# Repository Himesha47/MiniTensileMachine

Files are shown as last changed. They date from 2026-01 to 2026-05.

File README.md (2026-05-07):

# 🔬 MiniTensileMachine

A low-cost, open-source **miniature tensile testing machine** built as a Final Year Research project. The system uses an Arduino-controlled stepper motor to apply tensile load to a specimen, while a Python GUI provides real-time data acquisition, live plotting, and materials analysis.

---

## 📌 Project Overview

Traditional tensile testing machines are expensive and inaccessible for small research labs or educational use. This project demonstrates that accurate tensile testing can be achieved with affordable off-the-shelf components and custom software, making it suitable for polymer films, paper, textiles, and other low-strength materials.

---

## 🛠️ Hardware Components

| Component | Role |
|---|---|
| Arduino Uno | Microcontroller — reads sensors and drives the motor |
| A4988 Stepper Driver | Controls the NEMA stepper motor for precise crosshead movement |
| HX711 Load Cell Amplifier | Amplifies the load cell signal for Arduino |
| Load Cell (strain gauge) | Measures applied force in Newtons |
| NEMA Stepper Motor | Drives the crosshead (UP / DOWN) |
| Custom PCB | Integrates all components cleanly |

---

## 💻 Software

### Python GUI — `tensile_tester_guiV5.py`

The main application (`gui/tensile_tester_guiV5.py`) is a full-featured desktop GUI built with **Tkinter** and **Matplotlib**.

#### Features

- 🔌 **Auto-connect to Arduino** — detects the correct COM port automatically on startup
- ▶️ **Start / Stop test control** — sends commands to Arduino over serial
- ↕️ **Motor direction control** — UP / DOWN before a test begins
- ⚖️ **Tare & Zero Length** — zero the load cell and displacement reference
- 📊 **Live real-time plotting** with 4 selectable graph modes:
  - Force vs Time
  - Displacement vs Time
  - Force vs Displacement
  - Stress vs Strain
- 🗃️ **Six live metric cards** — Current Force, Current Displacement, Peak Force, Peak Displacement, Break Force, Young's Modulus
- 🧮 **Automatic calculations**:
  - Cross-sectional area (Width × Thickness)
  - Engineering stress (Force / Area)
  - Engineering strain (Displacement / L₀)
  - Young's Modulus (least-squares fit over elastic region)
- 💥 **Fracture detection** — automatically stops the test when force drops >30% from peak
- 📁 **Export** — saves data as `.csv` and the current graph as a high-res `.png` into `results/`
- 🔄 **40-point moving average** — smooths noisy sensor readings in real time

---

## 📂 Project Structure

```
MiniTensileMachine/
│
├── firmware/
│   ├── tensile_machine/           # Active firmware (upload this to the Arduino)
│   │   └── tensile_machine.ino
│   └── archive/                   # Earlier experimental sketches (reference only)
│
├── gui/
│   ├── tensile_tester_guiV5.py   # Main Python GUI application
│   └── archive/                   # Older GUI versions (reference only)
│
├── hardware/
│   └── pcb/                       # KiCad PCB and schematic files
│
├── data/
│   └── specimens/                 # Raw .txt data from manual test runs
│
├── results/                       # Exported test data (CSV + PNG plots, git-ignored)
│   └── .gitkeep
│
├── requirements.txt               # Python dependencies
└── README.md
```

---

## ⚙️ Setup & Usage

### Requirements

- Python 3.8+ with `tkinter` (included with standard Python on Windows)
- Install dependencies:

```bash
pip install -r requirements.txt
```

### Running the Application

1. Upload `firmware/tensile_machine/tensile_machine.ino` to the Arduino Uno.
2. Connect the Arduino via USB.
3. Run the GUI:

```bash
cd gui
python tensile_tester_guiV5.py
```

4. The app will auto-detect the Arduino on the correct COM port.

### Performing a Test

1. (Optional) Enter **L₀**, **Width**, and **Thickness** for stress/strain calculations.
2. Select the desired **graph type** from the dropdown.
3. Click **TARE** to zero the load cell and **ZERO LEN** to zero the displacement.
4. Set the motor direction (**DIR UP** to pull the specimen).
5. Click **▶ START** to begin the test.
6. The machine will automatically stop when fracture is detected.
7. Click **EXPORT** to save the data and plot — the dialog opens in `results/` by default.

---

## 📈 Measured Outputs

| Parameter | Unit | Description |
|---|---|---|
| Force | N | Applied tensile load |
| Displacement | mm | Crosshead travel distance |
| Stress | MPa | Force / Cross-sectional area |
| Strain | — | Displacement / Gauge length (L₀) |
| Young's Modulus | MPa | Slope of the elastic region (E = σ/ε) |
| Peak Force | N | Maximum force reached during the test |
| Break Force | N | Force at the moment of specimen fracture |

---

## 📡 Serial Communication Protocol

The Arduino sends comma-separated data lines at 9600 baud:

```
t_ms,force_N,disp_mm       ← header sent at boot
1234,5.62,0.031             ← data line (time ms, force N, displacement mm)
```

The GUI sends text commands to the Arduino:

| Command | Action |
|---|---|
| `START` | Begin test (motor ON, data streaming) |
| `STOP` | Stop motor |
| `DIR UP` | Set motor direction to UP (tension) |
| `DIR DOWN` | Set motor direction to DOWN |
| `TARE` | Zero the load cell |
| `ZERO_LEN` | Zero the displacement sensor |

---

## 📸 Screenshots

> Exported test plots and data are saved to the `results/` folder.

---

## 👨‍🔬 Author

Final Year Research Project — Department of Physics 
Built with Arduino, Python, and custom PCB hardware.

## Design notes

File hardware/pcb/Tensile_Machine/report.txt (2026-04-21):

Info: Processing symbol 'A1:Module:Arduino_UNO_R3'.
Info: Processing symbol 'A2:Module:Pololu_Breakout-16_15.2x20.3mm'.
Info: Processing symbol 'C1:Capacitor_THT:C_Disc_D5.0mm_W2.5mm_P2.50mm'.
Info: Processing symbol 'C2:Capacitor_THT:CP_Radial_D8.0mm_P3.50mm'.
Info: Processing symbol 'J1:TerminalBlock:TerminalBlock_Xinya_XY308-2.54-4P_1x04_P2.54mm_Horizontal'.
Info: Processing symbol 'J2:TerminalBlock:TerminalBlock_Xinya_XY308-2.54-4P_1x04_P2.54mm_Horizontal'.
Info: Processing symbol 'J3:TerminalBlock:TerminalBlock_Xinya_XY308-2.54-2P_1x02_P2.54mm_Horizontal'.
Info: Processing symbol 'J4:TerminalBlock:TerminalBlock_Xinya_XY308-2.54-4P_1x04_P2.54mm_Horizontal'.
Info: Processing symbol 'J5:TerminalBlock:TerminalBlock_Xinya_XY308-2.54-4P_1x04_P2.54mm_Horizontal'.
Add net unconnected-(A1-D2-Pad17).
Connected A1 pin 17 to unconnected-(A1-D2-Pad17).
Add net Net-(A1-D5).
Connected A1 pin 20 to Net-(A1-D5).
Add net unconnected-(A1-IOREF-Pad2).
Connected A1 pin 2 to unconnected-(A1-IOREF-Pad2).
Add net unconnected-(A1-AREF-Pad30).
Connected A1 pin 30 to unconnected-(A1-AREF-Pad30).
Add net /HX_DT.
Connected A1 pin 23 to /HX_DT.
Add net unconnected-(A1-3V3-Pad4).
Connected A1 pin 4 to unconnected-(A1-3V3-Pad4).
Add net unconnected-(A1-D7-Pad22).
Connected A1 pin 22 to unconnected-(A1-D7-Pad22).
Add net unconnected-(A1-D10-Pad25).
Connected A1 pin 25 to unconnected-(A1-D10-Pad25).
Add net unconnected-(A1-D6-Pad21).
Connected A1 pin 21 to unconnected-(A1-D6-Pad21).
Add net /DIR.
Connected A1 pin 19 to /DIR.
Add net unconnected-(A1-A3-Pad12).
Connected A1 pin 12 to unconnected-(A1-A3-Pad12).
Add net unconnected-(A1-NC-Pad1).
Connected A1 pin 1 to unconnected-(A1-NC-Pad1).
Add net unconnected-(A1-D13-Pad28).
Connected A1 pin 28 to unconnected-(A1-D13-Pad28).
Add net unconnected-(A1-D11-Pad26).
Connected A1 pin 26 to unconnected-(A1-D11-Pad26).
Add net unconnected-(A1-SDA/A4-Pad31).
Connected A1 pin 31 to unconnected-(A1-SDA/A4-Pad31).
Add net unconnected-(A1-D1/TX-Pad16).
Connected A1 pin 16 to unconnected-(A1-D1/TX-Pad16).
Add net +5V.
Connected A1 pin 5 to +5V.
Add net unconnected-(A1-A2-Pad11).
Connected A1 pin 11 to unconnected-(A1-A2-Pad11).
Add net unconnected-(A1-D12-Pad27).
Connected A1 pin 27 to unconnected-(A1-D12-Pad27).
Add net unconnected-(A1-A1-Pad10).
Connected A1 pin 10 to unconnected-(A1-A1-Pad10).
Add net /STEP.
Connected A1 pin 18 to /STEP.
Add net unconnected-(A1-~{RESET}-Pad3).
Connected A1 pin 3 to unconnected-(A1-~{RESET}-Pad3).
Add net GND.
Connected A1 pin 29 to GND.
Add net unconnected-(A1-SDA/A4-Pad13).
Connected A1 pin 13 to unconnected-(A1-SDA/A4-Pad13).
Add net unconnected-(A1-D0/RX-Pad15).
Connected A1 pin 15 to unconnected-(A1-D0/RX-Pad15).
Add net unconnected-(A1-VIN-Pad8).
Connected A1 pin 8 to unconnected-(A1-VIN-Pad8).
Add net unconnected-(A1-SCL/A5-Pad32).
Connected A1 pin 32 to unconnected-(A1-SCL/A5-Pad32).
Connected A1 pin 7 to GND.
Add net unconnected-(A1-SCL/A5-Pad14).
Connected A1 pin 14 to unconnected-(A1-SCL/A5-Pad14).
Add net unconnected-(A1-A0-Pad9).
Connected A1 pin 9 to unconnected-(A1-A0-Pad9).
Connected A1 pin 6 to GND.
Add net /HX_SCK.
Connected A1 pin 24 to /HX_SCK.
Updated A1 unit metadata.
Added A2 (footprint 'Module:Pololu_Breakout-16_15.2x20.3mm').
Changed REF** reference designator to A2.
Changed A2 value from Pololu_Breakout-16_15.2x20.3mm to Pololu_Breakout_A4988.
Updated A2 symbol association from  to /9ce11f0a-daac-48ad-9ff5-aed24f605efb.
Updated A2 fields.
Updated A2 sheetname to '/'.
Updated A2 sheetfile to 'Tensile_Machine.kicad_sch'.
Updated A2 footprint filters to 'Pololu*Breakout*15.2x20.3mm*'.
Connected A2 pin 15 to /STEP.
Connected A2 pin 11 to +5V.
Connected A2 pin 2 to +5V.
Add net +12V.
Connected A2 pin 8 to +12V.
Connected A2 pin 13 to +5V.
Connected A2 pin 16 to /DIR.
Connected A2 pin 12 to GND.
Connected A2 pin 10 to +5V.
Connected A2 pin 7 to GND.
Add net /1B.
Connected A2 pin 3 to /1B.
Connected A2 pin 9 to Net-(A1-D5).
Connected A2 pin 14 to +5V.
Add net /2B.
Connected A2 pin 6 to /2B.
Add net /2A.
Connected A2 pin 5 to /2A.
Add net /1A.
Connected A2 pin 4 to /1A.
Connected A2 pin 1 to GND.
Updated A2 unit metadata.
Added A1 (footprint 'Module:Arduino_UNO_R3').
Added C1 (footprint 'Capacitor_THT:C_Disc_D5.0mm_W2.5mm_P2.50mm').
Changed REF** reference designator to C1.
Changed C1 value from C_Disc_D5.0mm_W2.5mm_P2.50mm to 0.1uF.
Updated C1 symbol association from  to /a392f29e-6ea6-410c-80fb-69ff1eea6aba.
Updated C1 fields.
Updated C1 sheetname to '/'.
Updated C1 sheetfile to 'Tensile_Machine.kicad_sch'.
Updated C1 footprint filters to 'C_*'.
Connected C1 pin 1 to +5V.
Connected C1 pin 2 to GND.
Updated C1 unit metadata.
Changed REF** reference designator to A1.
Added C2 (footprint 'Capacitor_THT:CP_Radial_D8.0mm_P3.50mm').
Changed REF** reference designator to C2.
Changed C2 value from CP_Radial_D8.0mm_P3.50mm to 470uF.
Updated C2 symbol association from  to /1f514063-8875-4d03-a3e9-da0d240c9436.
Updated C2 fields.
Updated C2 sheetname to '/'.
Updated C2 sheetfile to 'Tensile_Machine.kicad_sch'.
Updated C2 footprint filters to 'CP_*'.
Connected C2 pin 2 to GND.
Connected C2 pin 1 to +12V.
Updated C2 unit metadata.
Updated A1 symbol association from  to /e0d1e556-8547-4fa6-a76f-a9a0838d3b23.
Added J1 (footprint 'TerminalBlock:TerminalBlock_Xinya_XY308-2.54-4P_1x04_P2.54mm_Horizontal').
Changed REF** reference designator to J1.
Changed J1 value from TerminalBlock_Xinya_XY308-2.54-4P_1x04_P2.54mm_Horizontal to Stepper motor.
Updated J1 symbol association from  to /26a67c83-a84e-4405-9260-f3302d5805dd.
Updated J1 fields.
Updated J1 sheetname to '/'.
Updated J1 sheetfile to 'Tensile_Machine.kicad_sch'.
Updated J1 footprint filters to 'Connector*:*_1x??_*'.
Connected J1 pin 1 to /1B.
Connected J1 pin 3 to /2A.
Connected J1 pin 4 to /2B.
Connected J1 pin 2 to /1A.
Updated J1 unit metadata.
Updated A1 fields.
Added J2 (footprint 'TerminalBlock:TerminalBlock_Xinya_XY308-2.54-4P_1x04_P2.54mm_Horizontal').
Changed REF** reference designator to J2.
Changed J2 value from TerminalBlock_Xinya_XY308-2.54-4P_1x04_P2.54mm_Horizontal to Load cell.
Updated J2 symbol association from  to /47c7611e-49ea-4230-a9ca-6c8d696261cc.
Updated J2 fields.
Updated J2 sheetname to '/'.
Updated J2 sheetfile to 'Tensile_Machine.kicad_sch'.
Updated J2 footprint filters to 'Connector*:*_1x??_*'.
Add net Net-(J2-Pin_1).
Connected J2 pin 1 to Net-(J2-Pin_1).
Add net Net-(J2-Pin_4).
Connected J2 pin 4 to Net-(J2-Pin_4).
Add net Net-(J2-Pin_2).
Connected J2 pin 2 to Net-(J2-Pin_2).
Add net Net-(J2-Pin_3).
Connected J2 pin 3 to Net-(J2-Pin_3).
Updated J2 unit metadata.
Updated A1 sheetname to '/'.
Added J3 (footprint 'TerminalBlock:TerminalBlock_Xinya_XY308-2.54-2P_1x02_P2.54mm_Horizontal').
Changed REF** reference designator to J3.
Changed J3 value from TerminalBlock_Xinya_XY308-2.54-2P_1x02_P2.54mm_Horizontal to Power supply.
Updated J3 symbol association from  to /e6d3ee77-a735-4ffe-a698-87d4fa4ca9e0.
Updated J3 fields.
Updated J3 sheetname to '/'.
Updated J3 sheetfile to 'Tensile_Machine.kicad_sch'.
Updated J3 footprint filters to 'Connector*:*_1x??_*'.
Connected J3 pin 2 to GND.
Connected J3 pin 1 to +12V.
Updated J3 unit metadata.
Updated A1 sheetfile to 'Tensile_Machine.kicad_sch'.
Added J4 (footprint 'TerminalBlock:TerminalBlock_Xinya_XY308-2.54-4P_1x04_P2.54mm_Horizontal').
Changed REF** reference designator to J4.
Changed J4 value from TerminalBlock_Xinya_XY308-2.54-4P_1x04_P2.54mm_Horizontal to HX711_LOAD.
Updated J4 symbol association from  to /d505f5b6-755c-469a-85d0-f86fedeb9e4e.
Updated J4 fields.
Updated J4 sheetname to '/'.
Updated J4 sheetfile to 'Tensile_Machine.kicad_sch'.
Updated J4 footprint filters to 'Connector*:*_1x??_*'.
Connected J4 pin 4 to Net-(J2-Pin_4).
Connected J4 pin 2 to Net-(J2-Pin_2).
Connected J4 pin 1 to Net-(J2-Pin_1).
Connected J4 pin 3 to Net-(J2-Pin_3).
Updated J4 unit metadata.
Updated A1 footprint filters to 'Arduino*UNO*R3*'.
Added J5 (footprint 'TerminalBlock:TerminalBlock_Xinya_XY308-2.54-4P_1x04_P2.54mm_Horizontal').
Changed REF** reference designator to J5.
Changed J5 value from TerminalBlock_Xinya_XY308-2.54-4P_1x04_P2.54mm_Horizontal to HX711_CTRL.
Updated J5 symbol association from  to /12e2f7dd-3db3-4ff2-9b89-f2648dfc7185.
Updated J5 fields.
Updated J5 sheetname to '/'.
Updated J5 sheetfile to 'Tensile_Machine.kicad_sch'.
Updated J5 footprint filters to 'Connector*:*_1x??_*'.
Connected J5 pin 4 to GND.
Connected J5 pin 3 to /HX_SCK.
Connected J5 pin 1 to +5V.
Connected J5 pin 2 to /HX_DT.
Updated J5 unit metadata.

Info: Total warnings: 0, errors: 0.

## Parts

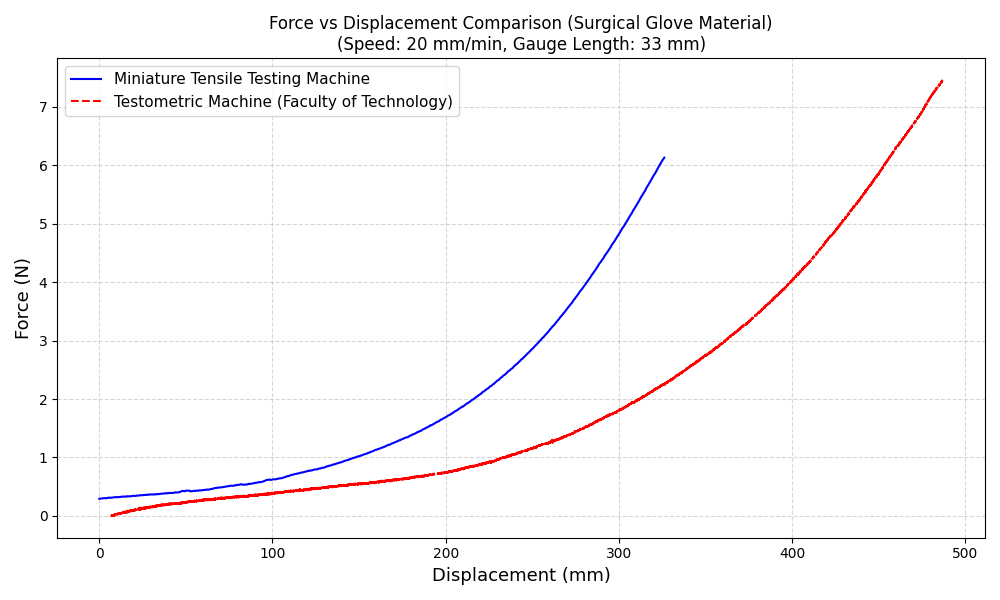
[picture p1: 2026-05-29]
MiniTensileMachine_Results/Glove Material/Glove_Comparison_FvD.png

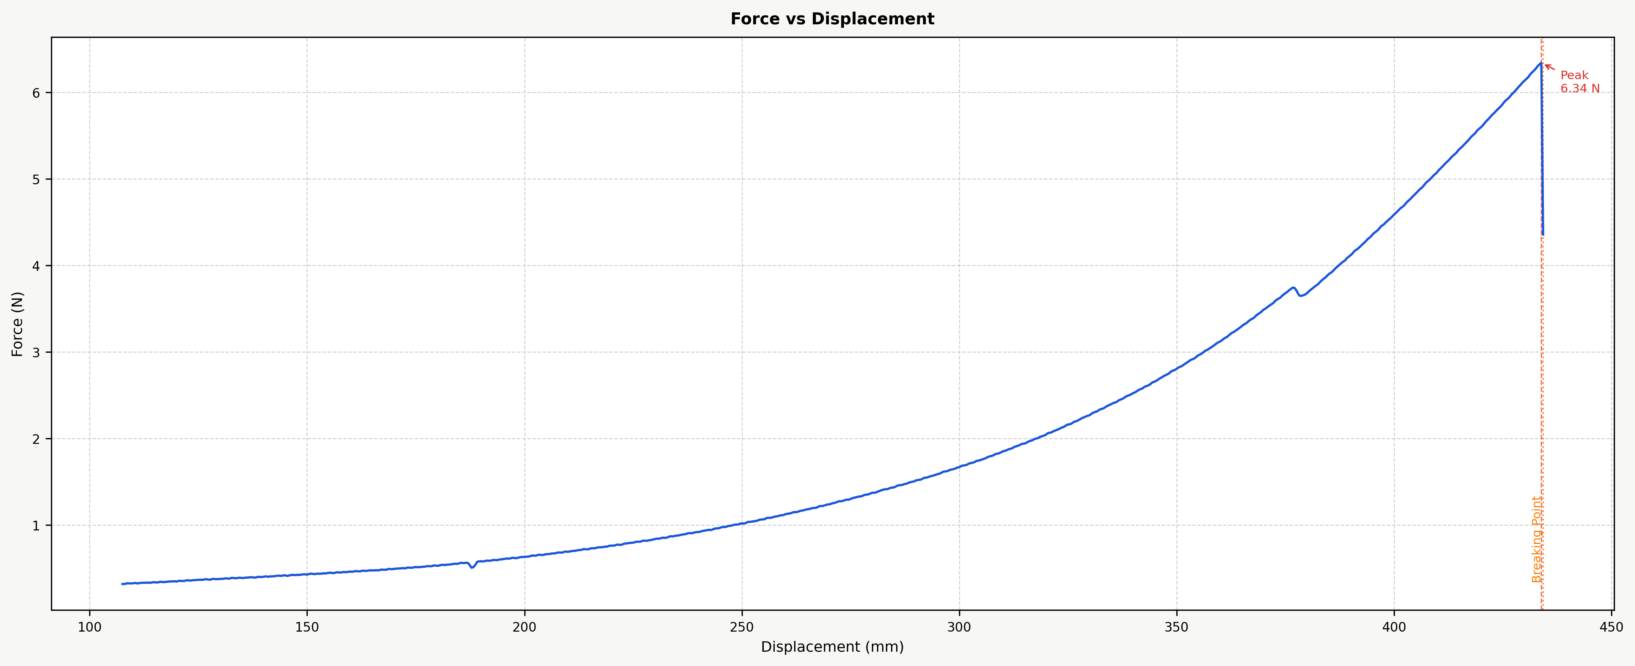
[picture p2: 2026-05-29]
MiniTensileMachine_Results/Glove Material/Glove2.png

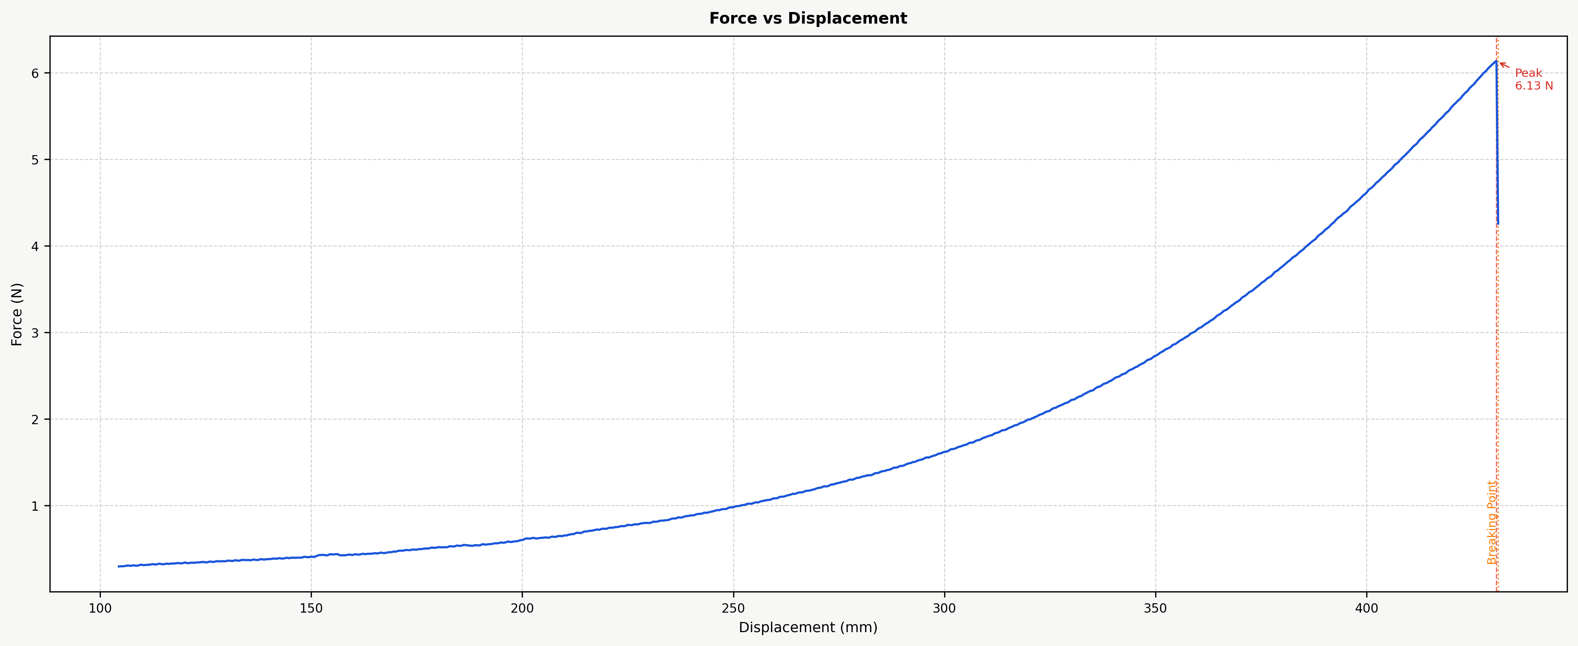
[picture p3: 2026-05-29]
MiniTensileMachine_Results/Glove Material/Glove3.png

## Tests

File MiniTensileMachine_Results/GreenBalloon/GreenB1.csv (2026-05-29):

Time (s) | Force (N) | Displacement (mm) | Strain | Stress (MPa)
476.732 | 0.6017125000000014 | 135.33047875 | 5.41321915 | 0.557141203703705
476.782 | 0.6018000000000014 | 135.34681375 | 5.41387255 | 0.5572222222222235
476.832 | 0.6018875000000014 | 135.36314875 | 5.41452595 | 0.557303240740742
476.882 | 0.6019125000000013 | 135.37948375000002 | 5.415179350000001 | 0.5573263888888901
476.932 | 0.6019375000000013 | 135.39582625 | 5.41583305 | 0.5573495370370383
476.982 | 0.6018500000000013 | 135.4121625 | 5.4164864999999995 | 0.5572685185185197
477.032 | 0.6017625000000013 | 135.42849875 | 5.417139949999999 | 0.5571875000000012
477.082 | 0.6016875000000013 | 135.444835 | 5.417793400000001 | 0.5571180555555567
477.132 | 0.6016125000000013 | 135.46117125 | 5.4184468500000005 | 0.5570486111111123
477.182 | 0.6015500000000014 | 135.4775075 | 5.4191003 | 0.556990740740742
477.232 | 0.6014875000000013 | 135.49384875 | 5.4197539500000005 | 0.5569328703703715
477.282 | 0.6015750000000013 | 135.510185 | 5.4204074 | 0.55701388888889
477.332 | 0.6016625000000013 | 135.52652125 | 5.42106085 | 0.5570949074074086
477.382 | 0.6019000000000013 | 135.5428575 | 5.4217143 | 0.557314814814816
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

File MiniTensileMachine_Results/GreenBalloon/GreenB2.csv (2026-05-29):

Time (s) | Force (N) | Displacement (mm) | Strain | Stress (MPa)
504.184 | 0.7915500000000021 | 160.18692249999998 | 6.407476899999999 | 0.7329166666666685
504.234 | 0.7916500000000021 | 160.2032575 | 6.4081303 | 0.7330092592592611
504.284 | 0.7916750000000021 | 160.21959375 | 6.4087837500000004 | 0.7330324074074094
504.334 | 0.7917000000000021 | 160.23593625 | 6.40943745 | 0.7330555555555575
504.384 | 0.7916625000000022 | 160.2522725 | 6.4100909 | 0.7330208333333352
504.434 | 0.7916250000000021 | 160.26860875 | 6.41074435 | 0.732986111111113
504.484 | 0.791612500000002 | 160.284945 | 6.4113978 | 0.7329745370370389
504.534 | 0.7916000000000021 | 160.30128125000002 | 6.412051250000001 | 0.7329629629629648
504.584 | 0.7915500000000021 | 160.3176225 | 6.4127049 | 0.7329166666666685
504.634 | 0.7915000000000021 | 160.33396375 | 6.413358550000001 | 0.7328703703703723
504.684 | 0.7912500000000021 | 160.3503 | 6.4140120000000005 | 0.7326388888888908
504.734 | 0.791000000000002 | 160.36663625 | 6.41466545 | 0.7324074074074093
504.784 | 0.790712500000002 | 160.3829725 | 6.4153189 | 0.7321412037037055
504.834 | 0.790425000000002 | 160.39930875 | 6.41597235 | 0.7318750000000018
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

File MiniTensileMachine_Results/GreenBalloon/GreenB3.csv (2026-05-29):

Time (s) | Force (N) | Displacement (mm) | Strain | Stress (MPa)
465.312 | 0.7429625000000026 | 147.42101 | 5.896840399999999 | 0.6879282407407431
465.362 | 0.7428625000000026 | 147.437345 | 5.8974937999999995 | 0.6878356481481506
465.412 | 0.7427625000000028 | 147.45368000000002 | 5.8981472 | 0.687743055555558
465.462 | 0.7428000000000028 | 147.47001625000001 | 5.898800650000001 | 0.6877777777777803
465.512 | 0.7428375000000027 | 147.4863525 | 5.899454100000001 | 0.6878125000000025
465.562 | 0.7429250000000027 | 147.50268875 | 5.90010755 | 0.687893518518521
465.612 | 0.7430125000000027 | 147.51903124999998 | 5.9007612499999995 | 0.6879745370370395
465.662 | 0.7431500000000028 | 147.5353675 | 5.9014147 | 0.6881018518518544
465.712 | 0.7432875000000028 | 147.55170375 | 5.90206815 | 0.6882291666666692
465.762 | 0.7434250000000027 | 147.56804 | 5.9027216 | 0.6883564814814839
465.812 | 0.7435625000000027 | 147.58437625 | 5.903375049999999 | 0.6884837962962987
465.862 | 0.7436625000000027 | 147.60071125 | 5.904028449999999 | 0.6885763888888913
465.912 | 0.7437625000000028 | 147.6170525 | 5.9046821 | 0.688668981481484
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

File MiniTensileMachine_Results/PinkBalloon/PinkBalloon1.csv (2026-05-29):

Time (s) | Force (N) | Displacement (mm) | Strain | Stress (MPa)
593.493 | 1.3607500000000012 | 173.9656975 | 5.798856583333333 | 0.22679166666666686
593.543 | 1.3611000000000013 | 173.98203375 | 5.799401125 | 0.22685000000000022
593.593 | 1.3613875000000013 | 173.99837 | 5.799945666666667 | 0.2268979166666669
593.643 | 1.3616750000000013 | 174.0147125 | 5.800490416666666 | 0.22694583333333354
593.693 | 1.3618500000000013 | 174.0310475 | 5.801034916666667 | 0.22697500000000023
593.743 | 1.3620250000000014 | 174.0473825 | 5.801579416666667 | 0.2270041666666669
593.793 | 1.3620875000000012 | 174.0637175 | 5.802123916666667 | 0.22701458333333355
593.843 | 1.362150000000001 | 174.08005375 | 5.802668458333333 | 0.22702500000000017
593.893 | 1.3622625000000013 | 174.09638999999999 | 5.8032129999999995 | 0.2270437500000002
593.943 | 1.3623750000000012 | 174.11272624999998 | 5.803757541666666 | 0.2270625000000002
593.993 | 1.3624500000000013 | 174.12905625000002 | 5.804301875000001 | 0.22707500000000022
594.043 | 1.362525000000001 | 174.14538625 | 5.804846208333333 | 0.2270875000000002
594.093 | 1.3626250000000013 | 174.16171624999998 | 5.805390541666666 | 0.22710416666666688
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

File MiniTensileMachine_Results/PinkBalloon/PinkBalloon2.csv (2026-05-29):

Time (s) | Force (N) | Displacement (mm) | Strain | Stress (MPa)
333.288 | 0.9214625000000012 | 104.67060375000001 | 3.4890201250000006 | 0.15357708333333353
333.338 | 0.9213625000000013 | 104.68693875 | 3.489564625 | 0.1535604166666669
333.388 | 0.9212625000000013 | 104.70326875 | 3.4901089583333333 | 0.15354375000000023
333.438 | 0.9213500000000012 | 104.71959875 | 3.490653291666667 | 0.15355833333333355
333.488 | 0.9214375000000011 | 104.73592875 | 3.491197625 | 0.15357291666666686
333.538 | 0.9215625000000012 | 104.75225875000001 | 3.491741958333334 | 0.1535937500000002
333.588 | 0.9216875000000012 | 104.768595 | 3.4922865 | 0.15361458333333353
333.639 | 0.9219250000000013 | 104.78493125 | 3.492831041666667 | 0.1536541666666669
333.689 | 0.9221625000000012 | 104.8012675 | 3.493375583333333 | 0.1536937500000002
333.739 | 0.9225125000000013 | 104.81760249999999 | 3.4939200833333333 | 0.15375208333333354
333.789 | 0.9228625000000011 | 104.8339375 | 3.4944645833333334 | 0.15381041666666687
333.839 | 0.9232125000000011 | 104.8502725 | 3.4950090833333336 | 0.1538687500000002
333.889 | 0.9235625000000012 | 104.86661375000001 | 3.495553791666667 | 0.15392708333333352
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

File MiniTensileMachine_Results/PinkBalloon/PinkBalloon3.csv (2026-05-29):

Time (s) | Force (N) | Displacement (mm) | Strain | Stress (MPa)
285.708 | 0.820274999999999 | 88.72663374999999 | 2.957554458333333 | 0.13671249999999982
285.758 | 0.8205249999999988 | 88.74297 | 2.958099 | 0.13675416666666648
285.808 | 0.8207499999999989 | 88.75930625 | 2.9586435416666665 | 0.13679166666666648
285.858 | 0.8209749999999989 | 88.7756475 | 2.95918825 | 0.13682916666666647
285.908 | 0.8211874999999991 | 88.79198249999999 | 2.9597327499999997 | 0.13686458333333318
285.958 | 0.821399999999999 | 88.8083175 | 2.96027725 | 0.13689999999999983
286.008 | 0.821512499999999 | 88.8246525 | 2.96082175 | 0.13691874999999984
286.058 | 0.8216249999999989 | 88.84098750000001 | 2.96136625 | 0.13693749999999982
286.108 | 0.821812499999999 | 88.85732375 | 2.961910791666667 | 0.13696874999999983
286.158 | 0.821999999999999 | 88.87366 | 2.962455333333333 | 0.13699999999999982
286.208 | 0.822162499999999 | 88.88999 | 2.9629996666666667 | 0.13702708333333316
286.258 | 0.822324999999999 | 88.90632000000001 | 2.963544 | 0.1370541666666665
286.308 | 0.822537499999999 | 88.92265 | 2.9640883333333337 | 0.13708958333333318
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

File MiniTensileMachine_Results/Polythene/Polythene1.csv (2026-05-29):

Time (s) | Force (N) | Displacement (mm) | Strain | Stress (MPa)
14.878 | 0.26102500000000217 | 0.32335875000000003 | 0.01293435 | 1.4186141304347943
14.928 | 0.31146250000000214 | 0.334955 | 0.0133982 | 1.6927309782608813
14.978 | 0.36190000000000216 | 0.34675625 | 0.013870249999999999 | 1.9668478260869684
15.028 | 0.4156375000000022 | 0.3587625 | 0.014350499999999999 | 2.258899456521751
15.078 | 0.4693750000000022 | 0.37097375 | 0.01483895 | 2.550951086956534
15.128 | 0.5247875000000022 | 0.38339 | 0.0153356 | 2.8521059782608815
24.032 | 0.5165000000000022 | 0.43215125 | 0.01728605 | 2.807065217391316
24.082 | 0.5081875000000022 | 0.48111750000000003 | 0.0192447 | 2.761888586956534
24.132 | 0.49001250000000224 | 0.53028875 | 0.02121155 | 2.6631114130434903
24.182 | 0.47183750000000224 | 0.57966 | 0.0231864 | 2.564334239130447
24.232 | 0.4534750000000022 | 0.62923625 | 0.025169450000000003 | 2.4645380434782727
24.282 | 0.4350875000000022 | 0.6790174999999999 | 0.027160699999999996 | 2.3646059782608813
24.332 | 0.4165375000000022 | 0.7290037500000001 | 0.029160150000000003 | 2.2637907608695773
24.382 | 0.3979750000000022 | 0.779195 | 0.0311678 | 2.1629076086956642
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

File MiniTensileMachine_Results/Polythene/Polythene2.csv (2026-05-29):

Time (s) | Force (N) | Displacement (mm) | Strain | Stress (MPa)
20.095 | -2.215562499999997 | 0.2619725 | 0.0104789 | -12.041100543478246
20.145 | -2.216212499999997 | 0.27241375 | 0.01089655 | -12.044633152173898
20.195 | -2.216749999999997 | 0.28306 | 0.0113224 | -12.047554347826072
20.245 | -2.217299999999997 | 0.29391124999999996 | 0.011756449999999998 | -12.050543478260854
20.295 | -2.217699999999997 | 0.3049675 | 0.0121987 | -12.052717391304332
20.346 | -2.218099999999997 | 0.31622875 | 0.01264915 | -12.05489130434781
20.396 | -2.218574999999997 | 0.32769499999999996 | 0.013107799999999998 | -12.05747282608694
20.446 | -2.219087499999997 | 0.33936625 | 0.013574649999999999 | -12.060258152173898
20.496 | -2.219574999999997 | 0.35124374999999997 | 0.014049749999999998 | -12.062907608695637
20.546 | -2.2200499999999974 | 0.36332624999999996 | 0.014533049999999999 | -12.065489130434768
20.596 | -2.220449999999997 | 0.37561374999999997 | 0.01502455 | -12.067663043478245
20.646 | -2.2208374999999974 | 0.3881 | 0.015524 | -12.069769021739116
20.696 | -2.221137499999997 | 0.40079125 | 0.016031649999999998 | -12.071399456521723
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

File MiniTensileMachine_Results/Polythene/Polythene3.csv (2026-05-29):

Time (s) | Force (N) | Displacement (mm) | Strain | Stress (MPa)
16.451 | -1.2279124999999969 | 0.11179125000000001 | 0.004471650000000001 | -6.673437499999983
16.501 | -1.200249999999997 | 0.11865250000000001 | 0.0047461000000000005 | -6.52309782608694
16.551 | -1.172587499999997 | 0.1257125 | 0.0050285 | -6.372758152173897
16.601 | -1.142987499999997 | 0.13297874999999998 | 0.005319149999999999 | -6.211888586956505
16.651 | -1.1133874999999969 | 0.14045000000000002 | 0.005618000000000001 | -6.051019021739114
16.701 | -1.081874999999997 | 0.14812625 | 0.005925049999999999 | -5.879755434782592
16.751 | -1.050362499999997 | 0.15600750000000002 | 0.006240300000000001 | -5.70849184782607
16.801 | -1.017024999999997 | 0.1640875 | 0.0065635 | -5.527309782608679
16.851 | -0.983687499999997 | 0.17237249999999998 | 0.006894899999999999 | -5.346127717391289
16.901 | -0.948637499999997 | 0.18086249999999998 | 0.0072345 | -5.155638586956505
16.951 | -0.913587499999997 | 0.1895575 | 0.007582299999999999 | -4.965149456521723
17.001 | -0.8768124999999969 | 0.1984575 | 0.0079383 | -4.76528532608694
17.051 | -0.840037499999997 | 0.2075625 | 0.0083025 | -4.565421195652157
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

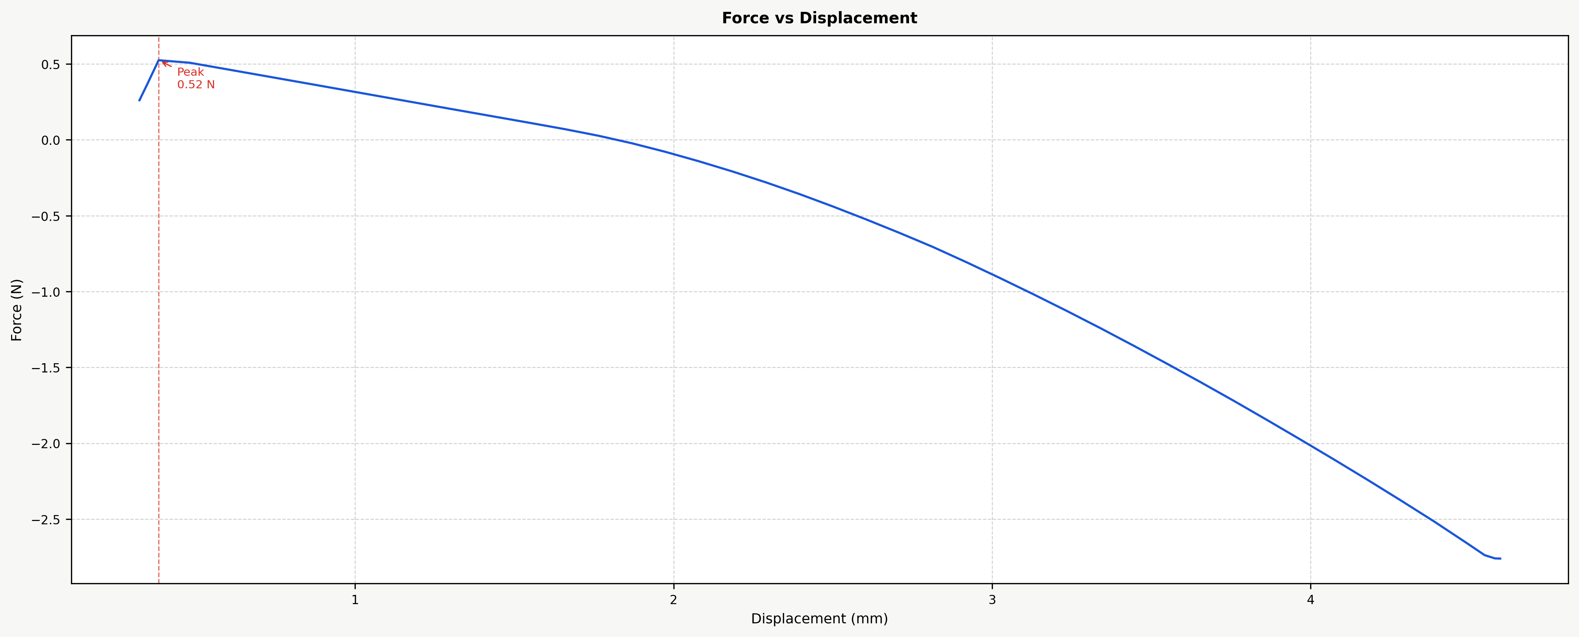
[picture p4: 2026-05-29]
MiniTensileMachine_Results/Polythene/Polythene1.png

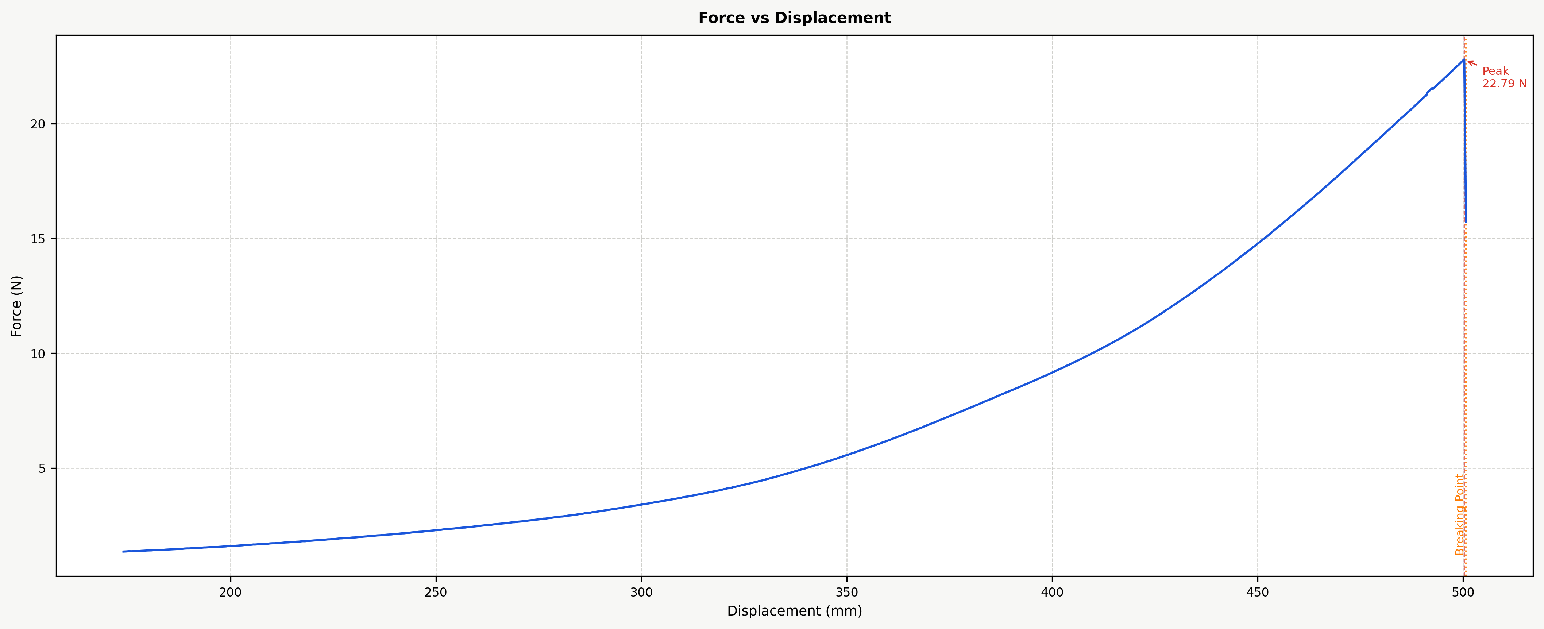
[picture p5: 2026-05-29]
MiniTensileMachine_Results/PinkBalloon/PinkBalloon1.png

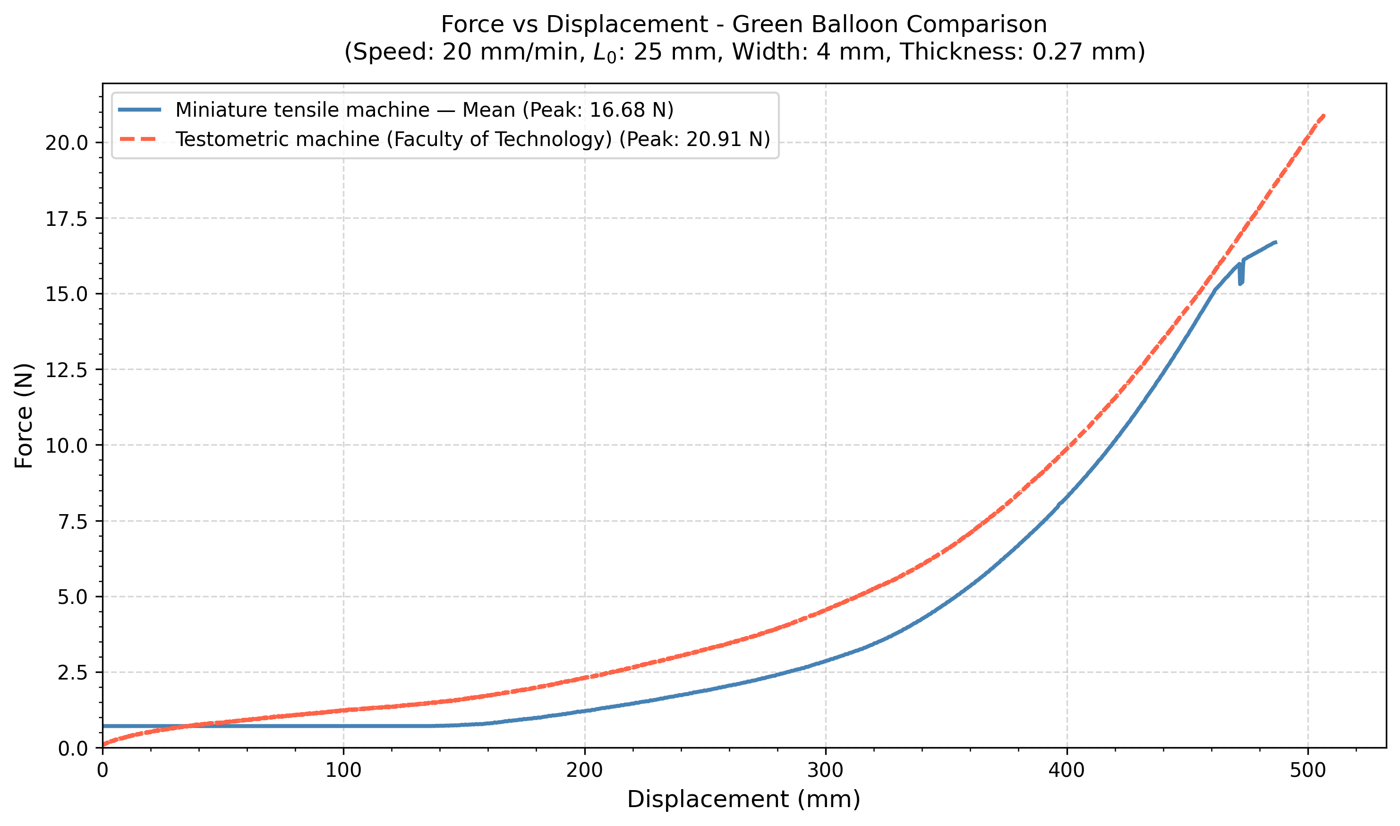
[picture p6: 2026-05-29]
MiniTensileMachine_Results/GreenBalloon/GreenB_Comparison_Mean_vs_Testometric.png

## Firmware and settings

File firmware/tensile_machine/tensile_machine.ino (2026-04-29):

#include "HX711.h"

//======================================================
// 1) PINS
//======================================================

// HX711
const int HX_DOUT = 8;
const int HX_SCK = 9;
HX711 loadCell;

// A4988 - step/dir/enable
const int PIN_STEP = 3;
const int PIN_DIR = 4;
const int PIN_EN = 5;   // ACTIVE LOW

// A4988 - microstepping pins
const int PIN_MS1 = 10;
const int PIN_MS2 = 11;
const int PIN_MS3 = 12;

//======================================================
// 2) SETTINGS
//======================================================

const int motorStepsPerRev = 200;
const float threadbarPitch_mmPerRev = 1.5;

// Current speed state — defaults to 50 mm/min
int microstepFactor = 16;
unsigned long stepPeriodUs = 563UL;  // Default 50 mm/min

float mmPerStep() {
  return threadbarPitch_mmPerRev / (motorStepsPerRev * microstepFactor);
}

// Calibration factor — determined experimentally during load cell calibration
float countsPerNewton = 10698.0;

//======================================================
// 3) STATE
//======================================================

bool runningTest = false;

long stepCount = 0;
int  dirSign = +1;

long  rawForce = 0;
float forceN = 0.0;

const unsigned long STREAM_PERIOD_MS = 50;
unsigned long lastStreamMs = 0;

unsigned long lastStepUs = 0;

unsigned long lastForceReadMs = 0;
const unsigned long FORCE_READ_MS = 100;

//======================================================
// 4) HELPERS
//======================================================

void enableDriver(){ digitalWrite(PIN_EN, LOW); }
void disableDriver(){ digitalWrite(PIN_EN, HIGH); }

float rawToNewton(long raw){
  return raw / countsPerNewton;
}

bool waitForReady(unsigned long timeoutMs){
  unsigned long t0 = millis();
  while (!loadCell.is_ready()) {
    if (millis() - t0 > timeoutMs) return false;
  }
  return true;
}

void doStepPulse(){
  digitalWrite(PIN_STEP, HIGH);
  delayMicroseconds(5);
  digitalWrite(PIN_STEP, LOW);
}

// Set MS1, MS2, MS3 pins according to microstep factor
// These pins control how many microsteps per full step
void setMicrostepPins(int factor) {
  switch (factor){
    case 1:   // Full step — MS1=L MS2=L MS3=L
      digitalWrite(PIN_MS1, LOW);
      digitalWrite(PIN_MS2, LOW);
      digitalWrite(PIN_MS3, LOW);
      break;
    case 2:   // Half step — MS1=H MS2=L MS3=L
      digitalWrite(PIN_MS1, HIGH);
      digitalWrite(PIN_MS2, LOW);
      digitalWrite(PIN_MS3, LOW);
      break;
    case 4:   // Quarter step— MS1=L MS2=H MS3=L
      digitalWrite(PIN_MS1, LOW);
      digitalWrite(PIN_MS2, HIGH);
      digitalWrite(PIN_MS3, LOW);
      break;
    case 8:   // Eighth step — MS1=H MS2=H MS3=L
      digitalWrite(PIN_MS1, HIGH);
      digitalWrite(PIN_MS2, HIGH);
      digitalWrite(PIN_MS3, LOW);
      break;
    case 16:  // Sixteenth step— MS1=H MS2=H MS3=H
      digitalWrite(PIN_MS1, HIGH);
      digitalWrite(PIN_MS2, HIGH);
      digitalWrite(PIN_MS3, HIGH);
      break;
    default:
      // Default to sixteenth step if unknown factor given
      digitalWrite(PIN_MS1, HIGH);
      digitalWrite(PIN_MS2, HIGH);
      digitalWrite(PIN_MS3, HIGH);
      microstepFactor = 16;
      break;
  }
}

// Set speed — updates both microstep factor and step period together
// Speed formula: speed = (1,000,000 / stepPeriodUs) x mmPerStep x 60
// Speed can only be changed when test is not running — enforced in command handler
void setSpeed(int speedMmPerMin) {
  switch (speedMmPerMin) {
    case 10:
      microstepFactor = 16;
      stepPeriodUs = 2813UL;  // 355.6 steps/sec: 10 mm/min
      break;
    case 20:
      microstepFactor = 16;
      stepPeriodUs = 1406UL;  // 711.1 steps/sec: 20 mm/min
      break;
    case 50:
      microstepFactor = 16;
      stepPeriodUs = 563UL;   // 1777.8 steps/sec: 50 mm/min
      break;
    case 100:
      microstepFactor = 8;
      stepPeriodUs = 563UL;   // 1777.8 steps/sec: 100 mm/min
      break;
    default:
      microstepFactor = 16;
      stepPeriodUs = 563UL;
      break;
  }
  setMicrostepPins(microstepFactor);
}

//======================================================
// 5) COMMANDS
//======================================================

void handleSerialCommands() {
  if (!Serial.available()) return;

  String cmd = Serial.readStringUntil('\n');
  cmd.trim();
  cmd.toUpperCase();

  if (cmd == "START") {
    runningTest = true;
    enableDriver();
    Serial.println("OK START");
  }

  else if (cmd == "STOP") {
    runningTest = false;
    disableDriver();
    Serial.println("OK STOP");
  }

  else if (cmd == "ZERO_LEN") {
    stepCount = 0;
    Serial.println("OK ZERO_LEN");
  }

  else if (cmd == "TARE") {
    if (waitForReady(1500)) {
      loadCell.tare(10);
      Serial.println("OK TARE");
    } else {
      Serial.println("ERR HX711_NOT_READY");
    }
  }

  else if (cmd == "DIR UP") {
    if (!runningTest) {
      digitalWrite(PIN_DIR, HIGH);
      dirSign = +1;
      Serial.println("OK DIR_UP");
    } else {
      Serial.println("ERR STOP_FIRST");
    }
  }

  else if (cmd == "DIR DOWN") {
    if (!runningTest) {
      digitalWrite(PIN_DIR, LOW);
      dirSign = -1;
      Serial.println("OK DIR_DOWN");
    } else {
      Serial.println("ERR STOP_FIRST");
    }
  }

  // Speed commands — only accepted when test is not running
  // If sent during a test, Arduino replies ERR STOP_FIRST
  else if (cmd == "SPEED_10") {
    if (!runningTest) {
      setSpeed(10);
      Serial.print("OK SPEED_10");
    } else {
      Serial.println("ERR STOP_FIRST");
    }
  }

  else if (cmd == "SPEED_20") {
    if (!runningTest) {
      setSpeed(20);
      Serial.print("OK SPEED_20 ");
    } else {
      Serial.println("ERR STOP_FIRST");
    }
  }

  else if (cmd == "SPEED_50") {
    if (!runningTest) {
      setSpeed(50);
      Serial.print("OK SPEED_50");
    } else {
      Serial.println("ERR STOP_FIRST");
    }
  }

  else if (cmd == "SPEED_100") {
    if (!runningTest) {
      setSpeed(100);
      Serial.print("OK SPEED_100");
    } else {
      Serial.println("ERR STOP_FIRST");
    }
  }
}

//======================================================
// 6) SETUP
//======================================================

void setup() {
  Serial.begin(9600);
  delay(800);

  pinMode(PIN_STEP, OUTPUT);
  pinMode(PIN_DIR,OUTPUT);
  pinMode(PIN_EN, OUTPUT);
  pinMode(PIN_MS1, OUTPUT);
  pinMode(PIN_MS2,OUTPUT);
  pinMode(PIN_MS3,OUTPUT);

  disableDriver();
  digitalWrite(PIN_DIR, HIGH);
  dirSign = +1;

  // Default speed: 50 mm/min on startup
  setSpeed(50);

  loadCell.begin(HX_DOUT, HX_SCK);

  Serial.println("BOOT OK");
  Serial.println("t_ms,force_N,disp_mm");
}

//======================================================
// 7) LOOP
//======================================================

void loop() {
  handleSerialCommands();

  // Read load cell every 100 ms
  unsigned long nowForceMs = millis();
  if (loadCell.is_ready() && nowForceMs - lastForceReadMs >= FORCE_READ_MS) {
    lastForceReadMs = nowForceMs;
    rawForce = loadCell.read();
    forceN = rawToNewton(rawForce);
  }

  float disp_mm = stepCount * mmPerStep();

  // Stream data every 50 ms — sends even when test is not running
  // so Python always has live force and displacement readings
  unsigned long nowMs = millis();
  if (nowMs - lastStreamMs >= STREAM_PERIOD_MS) {
    lastStreamMs = nowMs;
    Serial.print(nowMs);
    Serial.print(",");
    Serial.print(forceN, 3);
    Serial.print(",");
    Serial.println(disp_mm, 4);
  }

  if (!runningTest) {
    delay(10);
    return;
  }

  // Motor stepping — only runs when test is active
  // Checks if enough time has passed since last step
  // stepPeriodUs controls the speed — smaller = faster
  unsigned long nowMicros = micros();
  if (nowMicros - lastStepUs >= stepPeriodUs) {
    lastStepUs = nowMicros;
    doStepPulse();
    stepCount += dirSign;
  }
}

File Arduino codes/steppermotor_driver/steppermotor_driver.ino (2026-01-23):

// NEMA 17 + A4988 + 1 mm pitch + 1/8 microstepping

// Control pins from Arduino to A4988
const int STEP_PIN = 3;    // Each pulse on this pin = 1 microstep
const int DIR_PIN  = 4;    // Direction: HIGH = CW, LOW = CCW

// Microstepping selection pins
const int MS1_PIN  = 5;
const int MS2_PIN  = 6;
const int MS3_PIN  = 7;

// Enable pin (turns driver on/off)
const int EN_PIN   = 8;    // LOW = enabled, HIGH = disabled

// Motor: 200 full steps per revolution for NEMA17
const int STEPS_PER_REV_FULL = 200;

//  1/8 microstepping
const int MICROSTEP_MODE = 8;

// Total microsteps per revolution
const int MICROSTEPS_PER_REV = STEPS_PER_REV_FULL * MICROSTEP_MODE;

// Size of one microstep in mm
const float MICROSTEP_SIZE_MM = 1.0 / MICROSTEPS_PER_REV;  // 0.000625 mm

const int DEFAULT_DELAY_US = 800;  

void stepMotor(long steps, int delayUs) {
  for (long i = 0; i < steps; i++) {
    digitalWrite(STEP_PIN, HIGH);       // Rising edge = take one microstep
    delayMicroseconds(delayUs);         // Control speed
    digitalWrite(STEP_PIN, LOW);        // End of pulse
    delayMicroseconds(delayUs);         // Pause before next microstep
  }
}

void moveMM(float mm, bool moveDown, int delayUs) {

  if (moveDown) {
    // Set direction pin so motor rotates clockwise (cross arm moves DOWN)
    digitalWrite(DIR_PIN, HIGH);
  } else {
    // Set direction for anticlockwise (cross arm moves UP)
    digitalWrite(DIR_PIN, LOW);
  }

  // Calculate how many microsteps are needed for the requested distance
  // stepsNeeded = distance(mm) / step_size(mm per microstep)
  long stepsNeeded = mm / MICROSTEP_SIZE_MM;

  // Safety: avoid negative steps
  if (stepsNeeded < 0) {
    stepsNeeded = -stepsNeeded;
  }

  // Perform the movement
  stepMotor(stepsNeeded, delayUs);
}


// ---------- Arduino setup ----------
void setup() {
  // Set all relevant pins as outputs
  pinMode(STEP_PIN, OUTPUT);
  pinMode(DIR_PIN,  OUTPUT);

  pinMode(MS1_PIN,  OUTPUT);
  pinMode(MS2_PIN,  OUTPUT);
  pinMode(MS3_PIN,  OUTPUT);
  pinMode(EN_PIN,   OUTPUT);

  // Enable the stepper driver
  // A4988: EN LOW = enabled, EN HIGH = disabled
  digitalWrite(EN_PIN, LOW);

  // Configure microstepping to 1/8:
  // MS1 = HIGH, MS2 = HIGH, MS3 = LOW  -> 1/8 microstepping
  digitalWrite(MS1_PIN, HIGH);
  digitalWrite(MS2_PIN, HIGH);
  digitalWrite(MS3_PIN, LOW);
}


// ---------- Main loop (test behaviour only) ----------
void loop() {
  // Example test sequence:
  // 1) Move DOWN 1 mm
  // 2) Wait 1 second
  // 3) Move UP 1 mm
  // 4) Wait 1 second
  //
  // This is just for testing. Later you will replace this with:
  //  - limit switch logic
  //  - buttons
  //  - PC commands
  //  - test procedure, etc.

  // Move cross arm DOWN by 1.0 mm
  moveMM(1.0, true, DEFAULT_DELAY_US);   // true  = moveDown

  delay(1000);  // wait 1 second

  // Move cross arm UP by 1.0 mm
  moveMM(1.0, false, DEFAULT_DELAY_US);  // false = moveUp

  delay(1000);  // wait 1 second
}

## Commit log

2026-01-23 Updated the arduino codes.
    Tested the components seperately with the arduino codes and then finally tried to test all the components together.
2026-04-21 Refactor code structure for improved readability and maintainability
    [421T1.csv, 421T2.csv, Error_MotorVibration.csv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]
2026-04-29 feat: add tensile machine Arduino control firmware and Python GUI application variants
2026-04-29 refactor: clean up project structure
    - Remove old GUI versions (V1-V4), keep V5 as tensile_tester_gui.py
    - Move test data (CSVs, PNGs) to data/ directory (git-ignored)
    - Remove KiCad backup zips, lock files, and .history from tracking
    - Update .gitignore with comprehensive rules
    - Add requirements.txt for Python dependencies
    - Update README.md to reflect new project structure
    [421T1.csv, 421T2.csv, Error_MotorVibration.csv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]
2026-04-29 refactor: reorganise project structure and improve code quality
    - Move all loose CSV/PNG result files from root and data/ into results/
    - Remove now-empty data/ folder
    - Add results/.gitkeep so git tracks folder without tracking its contents
    - Update .gitignore: add results/ rule, !results/.gitkeep exception, logs/
    - Add requirements.txt (pyserial>=3.5, matplotlib>=3.7)
    - Refactor tensile_tester_guiV5.py:
    * Add module docstring with requirements note
    * Add logging module (replaces bare print)
    * Add pathlib for cross-platform path handling
    * Add Config dataclass centralising all constants
    * Keep module-level aliases so all existing code unchanged
    * EXPORT dialog now de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
    [421T1.csv, 421T2.csv, Error_MotorVibration.csv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]
2026-04-29 feat: add KiCad PCB files, Python control scripts, and Arduino firmware for tensile testing machine
    [Tensile_Machine.kicad_pcb, Tensile_Machine.kicad_sch]
2026-04-29 feat: initialize project structure with KiCad PCB files, Arduino controller firmware, and Python GUI application
    [Tensile_Machine.kicad_pcb, Tensile_Machine.kicad_sch]
2026-04-29 Add schematic components and connections for Tensile Machine
    - Added Arduino UNO R3 module (A1) and connected relevant pins.
    - Integrated Pololu Breakout A4988 module (A2) with power and control connections.
    - Included capacitors (C1: 0.1uF, C2: 470uF) with appropriate connections to power rails.
    - Added terminal blocks (J1-J5) for stepper motor, load cell, power supply, and control signals.
    - Established net connections for all components, ensuring proper functionality.
    - Updated metadata and footprint filters for all components in the schematic.
    [Tensile_Machine.kicad_pcb, Tensile_Machine.kicad_sch]
2026-05-29 Add experimental results folder
    [Glove2.csv, Glove3.csv, GreenB1.csv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]
